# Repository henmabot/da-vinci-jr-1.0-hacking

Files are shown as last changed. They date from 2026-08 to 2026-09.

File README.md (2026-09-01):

# Da Vinci Jr. 1.0 Hacking

There was a lot of efforts on reverse engineering/hacking this printer years ago, but nobody seemed to have done it fully due to various reasons. I have decided to continue over their work, and adding my own work while documenting my progress.

This repository is a mix of:

- Organization of the old community's findings
- My own work
- Official datasheets/documentation from manufacturers

I try to add source links whenever possible.

## Status

| Task Name  | Description | Status | Main Board | Sub Board | Hotend Board |
| --- | --- | --- | --- | --- | --- |
| Pinouts | Trace all of the pinouts of the printer | 85% | 40% | 100% | 90% |
| Schematics | Draw the schematics of the printer | 85% | 30% | 100% | 100% |
| Configs | Build firmware configs for the printer  | 0% | - | - | - |

## More Information

More information can be found in the [hardware](hardware.md) and [firmware](firmware.md) sections.

In case of doubts, refer to the KiCAD schematics for pinout information. All the pinouts in the schematics are verified, while some of the docs might be outdated or have typos.

Info about my personal progress on reverse engineering can be found in the [progress](PROGRESS.md) section.

## Other Boards

This repository is mainly for Da Vinci Jr series printers, but feel free to help extend it to other boards.

## Contributing

Any kind of contribution is welcome, whether it's a bug report, a feature request, or a pull request. I am open to any kind of feedback or suggestion, and I want to make this project better for everyone.

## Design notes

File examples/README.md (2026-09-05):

# Examples

This folder contains example firmware builds that you can download and flash.

The available examples are:

- [Blink](blink.bin) ([source](https://github.com/itsyumiki/da-vinci-jr-1.0-hacking/tree/bca9b8ce5da0e177e398c52942f69a1dbfcbf0b6))
- [GPIO controller](gpiodemo.bin) ([source](../gpiodemo))

> **How to flash?**
>
> You can use [BOSSA](https://github.com/shumatech/BOSSA) to flash the firmware: `bossac -p <port> -i -e -w -v blink.bin`
>
> More instructions about flashing and erasing the chip will be added in the future.

## Blink

The Blink example is a simple firmware that blinks the top light of the board. It also has USB CDC test, and repeatedly prints the status of the X axis endstop to the serial console.

If its triggered (hotend on left side), it will report high, and if not, it will report low.

Example output:

```
hello world 1, pd8 is high
hello world 2, pd8 is high
hello world 3, pd8 is high
hello world 4, pd8 is high
hello world 5, pd8 is high
hello world 6, pd8 is high
hello world 7, pd8 is high
hello world 8, pd8 is high
hello world 9, pd8 is low
hello world 10, pd8 is low
hello world 11, pd8 is low
```

> Its source code is available [here](https://github.com/itsyumiki/da-vinci-jr-1.0-hacking/tree/bca9b8ce5da0e177e398c52942f69a1dbfcbf0b6).

## GPIO controller

The GPIO controller firmware serves the request-ID protocol used by the Rust desktop controller over USB CDC. It supports pin direction, pull-up configuration, reads, writes, change listeners, state queries, and reset.

> Its source code and protocol documentation are available [here](../gpiodemo).

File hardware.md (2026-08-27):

# Da Vinci Jr. 1.0 Hardware

To start off, there are 3 boards in the Davinci Jr. 1.0:

- [Main Board](hardware/board-main.md)
- [Sub-Board](hardware/board-sub.md)
- [Hotend-Board](hardware/board-hotend.md)

## Main Board

Main components on the main board:

- 1x Atmel SAM4E8E MCU
- 1x NXP LPC1115 MCU
- 4x Stepper drivers
- 1x 4MB Flash memory

More info about the main board can be found in the [Main Board](hardware/board-main.md) section.

## Sub-board

Main components on the sub-board:

- 1x Character LCD 4x16
- 1x SD card reader
- 6x Buttons

More info about the sub-board can be found in the [Sub-Board](hardware/board-sub.md) section.

## Hotend

Components that I was able to identify on the hotend:

- 1x Heater
- 1x NTC
- 1x Fan
- 1x Filament sensor (?)
- 1x (?)KB Flash Memory

More info on these can be found in the [Hotend](hardware/board-hotend.md) section.

## Other Hardware

The remaining components that do not belong to a board are:

- 4x NEMA17 Stepper motors
- 3x Optical endstops
- 1x Filament sensor
- 1x RFID reader
- 1x Top light bar
- 1x Reflow fan

More info on these can be found in the [Other Hardware](hardware/board-other.md) section.

## Extras

I wasn't planning to identify the cables, but i do have to identify the flex cables and sensor cables as they are needed to figure out the pinouts for the sensors, sub-board and hotend.

More information about these can be found in the [connectors](hardware/connectors.md) section.

## Notes:

- I only identified the ones that need to be defined in the firmware, so no cable or passive components for now.
- I verified the pins by first attaching an external motor/sensor and then by plugging in the stock hardware and verifying the output is the same.
- Since hotend has its own board, and its tiny, I felt like it would be more appropriate to have it as its own group than dissect it into the other groups, and mention it from other docs.
- I will create a separate sources file later as the sources list keeps growing and duplicated per-document.
- My reflow fan controller is burnt, I may or may not be able to verify its pin.

## Sources:

Please refer to [SOURCES.md](SOURCES.md) for the full list of sources.

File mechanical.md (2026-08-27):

# Da Vinci Jr. 1.0 Mechanics

Soon to be populated, this will be the part with full BOM/parts list of the printer including exact screw counts of parts etc.

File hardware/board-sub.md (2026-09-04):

# Sub-board

The sub-board is the board for the interactivity of the printer. It has **6 push buttons, a 16x4 LCD display, and a full-size SD card slot**. It also has a **16 pin connector** labeled "SD CARD SLOT CONNECTOR", and a **22 pin connector** labeled "LCM SLOT CONNECTOR". It has no visible MCU's, only some power related chips and components. It also has no visible unpopulated headers, connectors and chip sockets.

| Front view of the board | Back view of the board |
| --- | --- |
| Front view | Back view |
| Front desoldered view | |

The board is **62mm to 185mm** in size.

**The components that i was able to identify so far are:**

- **1x** Winstar WH1604A 16x04 LCD module
- **1x** Generic SD card reader module
- **6x** Generic 6mm push buttons

There are some more chips that i didnt see as important, as they are passive or hardware driven. More information about these can be found in the [schematic](../schematic.md).

More information about the connectors on-board can be found in the [connectors](connectors.md) section.

## Winstar WH1604A 16x04 LCD module

The Winstar WH1604A 16x04 LCD module is a character LCD display that is used to display text on the sub-board. It has 16 columns and 4 rows of characters, and is connected to the main board via a 22 pin connector labeled "LCM SLOT CONNECTOR".

Refer to the [Winstar WH1604A 16x04 LCD Module Datasheet](../SOURCES.md#datasheet-winstar-wh1604a) for more information.

### Pinout

The connector mentioned here is the 22 pin connector.

| Pin | Name | Description | Connector Pin | Verified? | MCU Pin | Verified? |
| --- | ---- | --- | --- | --- | --- | --- |
| 01  | VSS  | Ground | GND | ✅ | GND | ✅ |
| 02  | VDD  | Supply Voltage for logic | 5V | ✅ | 5V | ✅ |
| 03  | VO | Operating voltage | - | ✅ | - | - |
| 04  | RS | H: DATA, L: Instruction code | 05 | ✅ |
| 05  | R/W  | H: Read L: Write | 04 | ✅ |
| 06  | E | Chip enable signal | 03 | ✅ |
| 07  | DB0  | Data bus line | 06 | ✅ |
| 08  | DB1  | Data bus line | 07 | ✅ |
| 09  | DB2  | Data bus line | 08 | ✅ |
| 10  | DB3  | Data bus line | 09 | ✅ |
| 11  | DB4  | Data bus line | 10 | ✅ |
| 12  | DB5  | Data bus line | 11 | ✅ |
| 13  | DB6  | Data bus line | 12 | ✅ |
| 14  | DB7  | Data bus line | 13 | ✅ |
| 15  | A | Backlight + | 5V | ✅ |
| 16  | K | Backlight - | 14 | ✅ |

### Photos

| Front view | Back view |
| --- | --- |
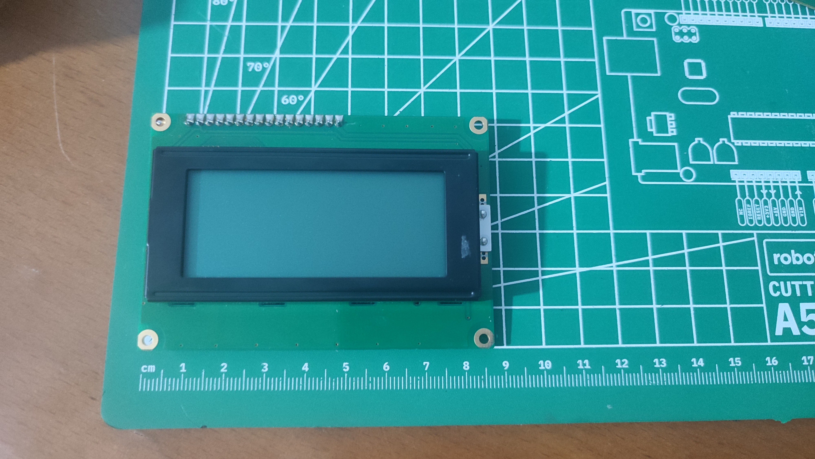
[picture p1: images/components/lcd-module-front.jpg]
Front view
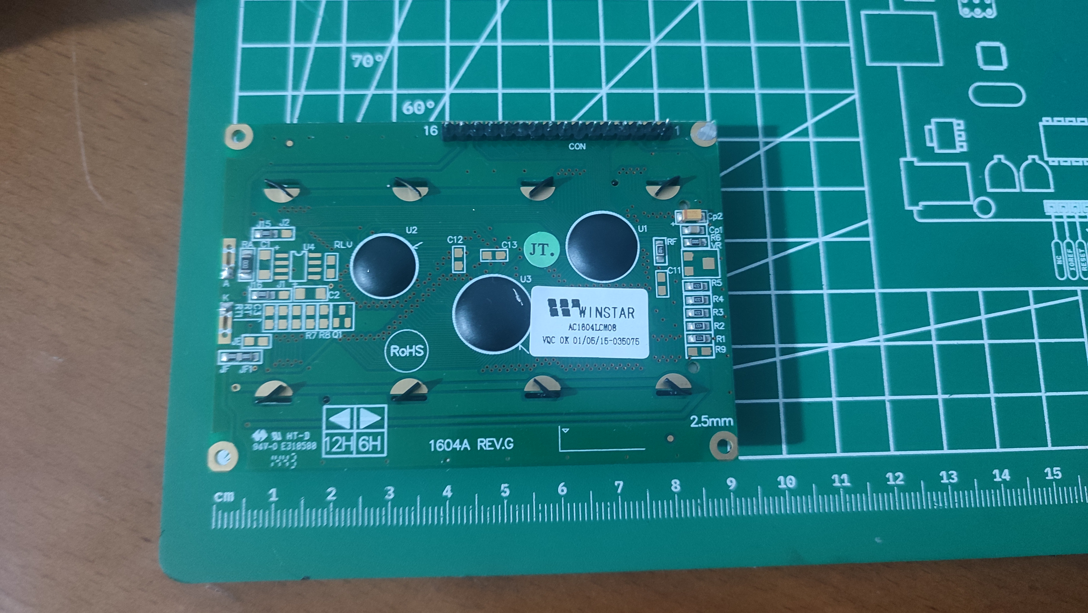
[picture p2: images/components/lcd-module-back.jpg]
Back view
|  |  |

## SD Card Reader Module

The SD card reader module is used to read full size SD cards and is connected to the main board via a 16 pin connector labeled "SD CARD SLOT CONNECTOR".

The WP and CD pins are grounded when they are triggered, like:

- No card inserted: CD is grounded
- Card inserted but write-protected: WP is grounded
- Card inserted and not write-protected: Both are floating/non-grounded

It is a generic SD card reader module, so there is no specific datasheet available.

### Pinout

Pins start from P1 (on the right of the reader) and go to the left, up to P11.

The connector mentioned here is the 16 pin connector.

| Pin | Name | Description | Connector Pin | Verified? | MCU Pin | Verified? |
| --- | --- | --- | --- | --- | --- | --- |
| 01  | DAT2 | - | 16 | ✅ | PA26 | ✅ |
| 02  | CS/DAT3 | Chip Select | 14 | ✅ | PA27 | ✅ |
| 03  | CMD | MOSI/Data in | 12 | ✅ | PA28 | ✅ |
| 04  | VSS1 | Ground | GND | ✅ | GND | ✅ |
| 05  | VDD | Power | 09 | ✅ | 3.3V | ✅ |
| 06  | CLK | SCK | 07 | ✅ | PA29 | ✅ |
| 07  | VSS2 | Ground | GND | ✅ | GND | ✅ |
| 08  | DAT0 | MISO | 05 | ✅ | PA30 | ✅ |
| 09  | DAT1 | - | 03 | ✅ | PA31 | ✅ |
| 10  | WP | Write Protect lock | - | ✅ | - | ✅ |
| 11  | CD | Card Detect | 10 | ✅ | PA25 | ✅ |

### Photos

| Top view of the SD card reader                       |
| ---------------------------------------------------- |
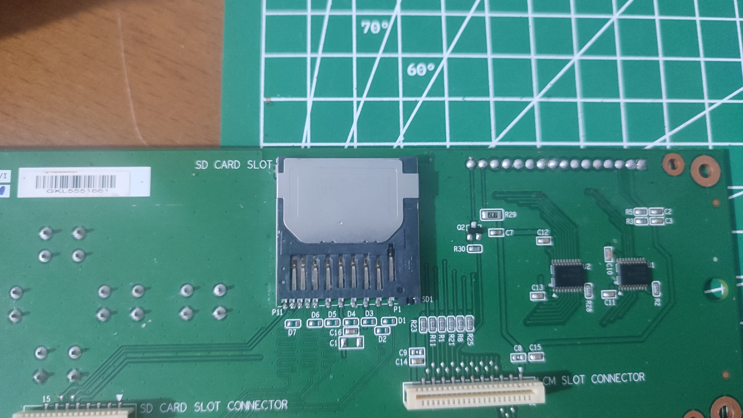
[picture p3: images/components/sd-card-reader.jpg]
|  |

## Push Buttons

The push buttons are used to control the sub-board and are connected to the main board via one of the existing connectors.

They are pulled up to 5V and grounded when pressed.

I doubt a datasheet for a button would be useful even.

### Pinout

The connector mentioned here is the 22 pin connector.

| Button | Name | Description  | Connector Pin | Verified? | MCU Pin | Verified? |
| --- | --- | --- | --- | --- | --- | --- |
| SW1 | UP | Up button | 18 | ✅ | PE1 | ✅ |
| SW2 | DOWN | Down button  | 16 | ✅ | PA21 | ✅ |
| SW3 | RIGHT  | Right button | 19 | ✅ | PE4 | ✅ |
| SW4 | LEFT | Left button  | 17 | ✅ | PB3 | ✅ |
| SW5 | ENTER  | Enter button | 20 | ✅ | PA17 | ✅ |
| SW6 | ESCAPE | Home button  | 15 | ✅ | PD30 | ✅ |

### Photos

| Top view of the push buttons                       |
| -------------------------------------------------- |
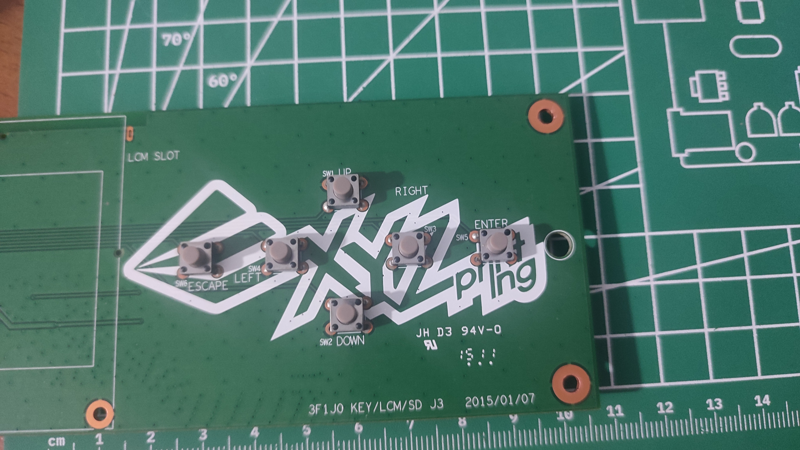
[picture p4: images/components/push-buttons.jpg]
|  |

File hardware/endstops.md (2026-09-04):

# Optical Endstops

There are 3 optical endstops on the printer. They share one connector labeled "Home Sensor".

## Pinout

| Pin Name  | MCU | Pin Desc | Verified? |
| --- | --- | --- | --- |
| X Endstop | 113 | PD8 | ✅ |
| Y Endstop | 117 | PC19 | ✅ |
| Z Endstop | 110 | PD9 | ✅ |

They are high when triggered, low when idle. They have hardware pull-up resistors on them. I am unsure about software pull-up being redundant.

## Photos

| In this photo all the endstops are visible after removal.          |
| ------------------------------------------------------------------ |
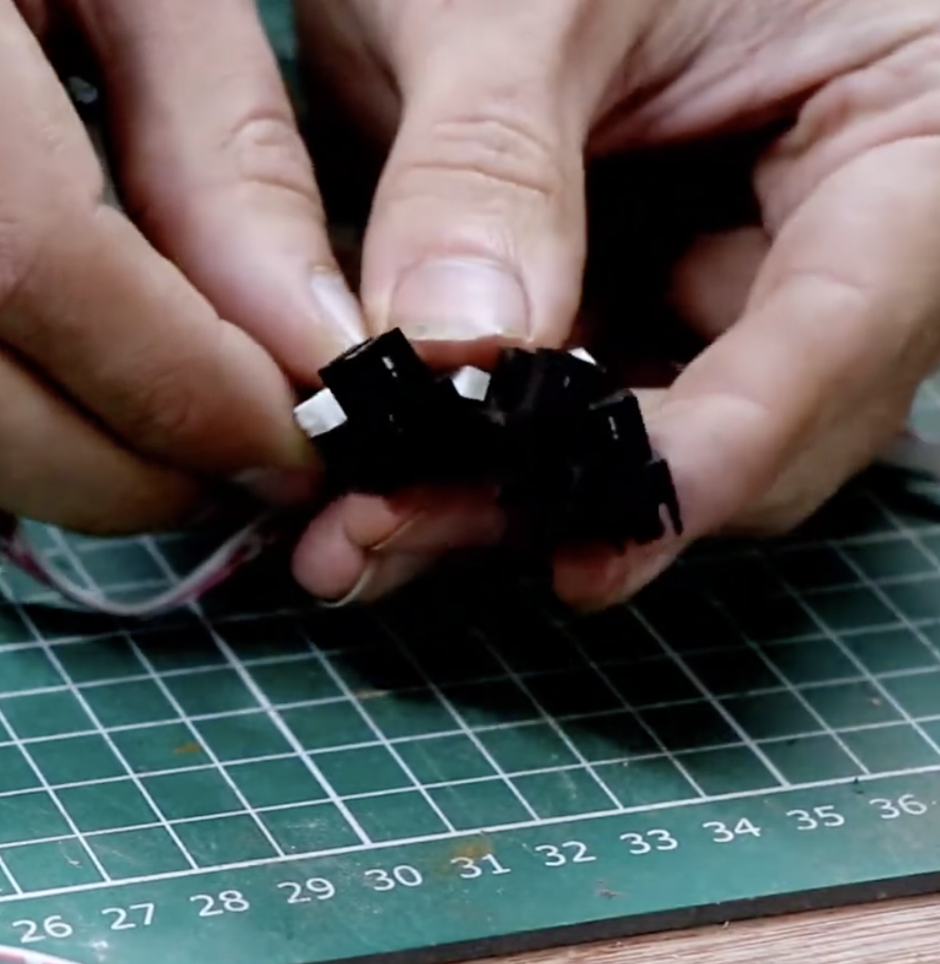
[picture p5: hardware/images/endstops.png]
All endstops after removal (YT)
|  |

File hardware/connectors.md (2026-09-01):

# Connectors

There are 3 main data connectors on the Da Vinci Jr 1.0 board.

- 22-pin LCD connector
- 16-pin SD Card connector
- 51-pin Hotend connector

There are of course a lot more connectors on board, but these are the main ones needing identification.

## 51-pin Hotend connector

The 51-pin Hotend connector connects the main board with the hotend. Its mostly power wires, and a few data wires.

### Photos

| Main board connector | Sub-board connector |
| --- | --- |
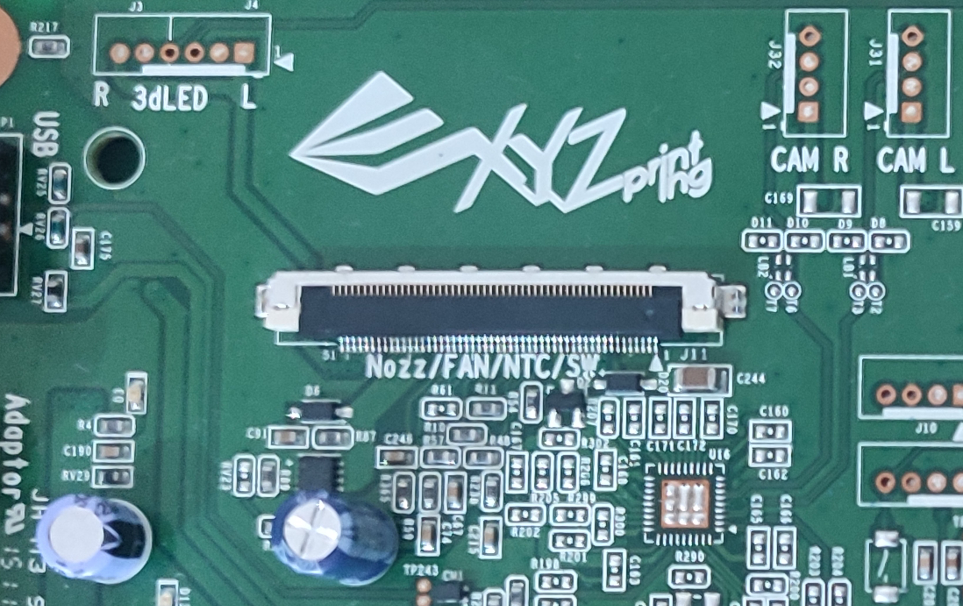
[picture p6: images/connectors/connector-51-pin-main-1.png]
Main board with text visible
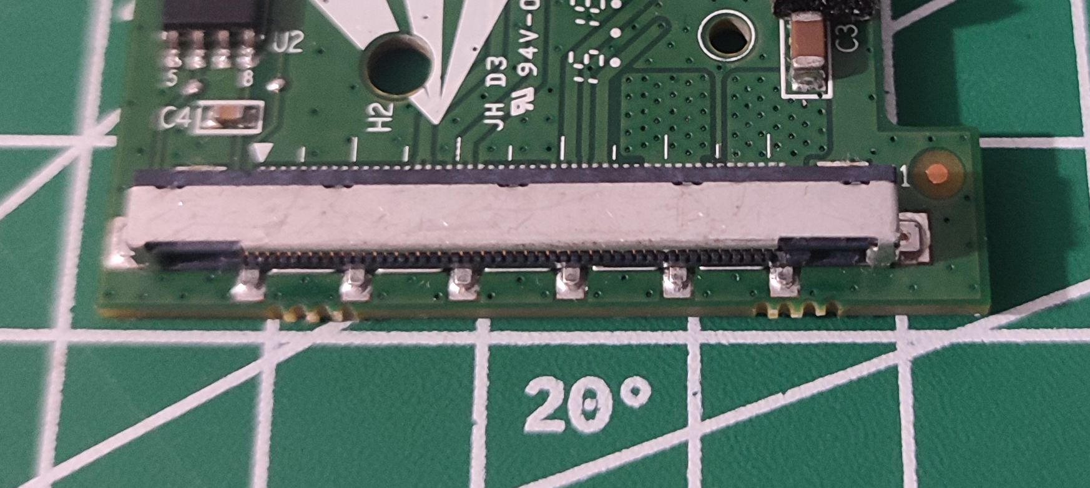
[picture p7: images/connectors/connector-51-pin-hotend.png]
|  |  |
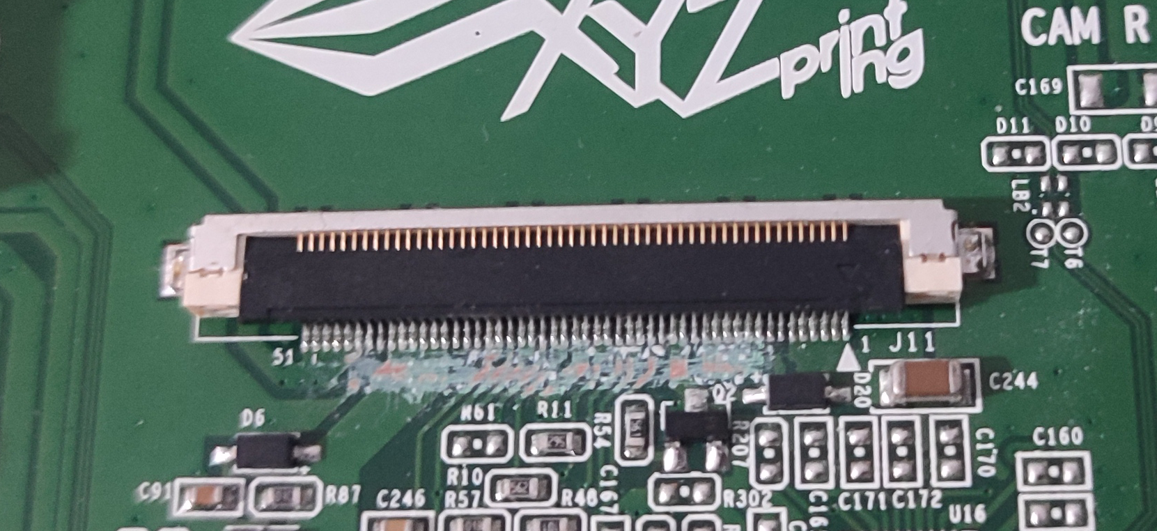
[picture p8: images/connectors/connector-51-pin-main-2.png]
Main board without text
|  | |

### Pinout

> Pins 1-6 and 46-51 are connected to each other, and they connect to the power via a fuse labeled R292 on board.
>
> IR sensor is the filament sensor. Its other end is connected to GND on the hotend, and its active low.
>
> J5 is a connector that I have no idea what it is for yet. I'm guessing its for calibrating the bed.

| Pin | Main board | Description | Verified? | Hotend | Description | Verified? |
| --- | --- | --- | --- | --- | --- | --- |
| 01  | 12V | Power 12V | ✅ | - | Not connected | ✅ |
| 02  | 12V | Power 12V | ✅ | - | Not connected | ✅ |
| 03  | 12V | Power 12V | ✅ | - | Not connected | ✅ |
| 04  | 12V | Power 12V | ✅ | - | Not connected | ✅ |
| 05  | 12V | Power 12V | ✅ | - | Not connected | ✅ |
| 06  | 12V | Power 12V | ✅ | - | Not connected | ✅ |
| 07  | - | Not connected | ✅ | - | Not connected | ✅ |
| 08  | - | Not connected | ✅ | - | Not connected | ✅ |
| 09  | Q8 5-8 | Mosfet drain  | ✅ | - | Not connected | ✅ |
| 10  | Q8 5-8 | Mosfet drain  | ✅ | - | Not connected | ✅ |
| 11  | Q8 5-8 | Mosfet drain  | ✅ | - | Not connected | ✅ |
| 12  | Q8 5-8 | Mosfet drain  | ✅ | - | Not connected | ✅ |
| 13  | Q8 5-8 | Mosfet drain  | ✅ | - | Not connected | ✅ |
| 14  | Q8 5-8 | Mosfet drain  | ✅ | - | Not connected | ✅ |
| 15  | - | Not connected | ✅ | - | Not connected | ✅ |
| 16  | Q2 3 | Transistor C  | ✅ | J2 1 | Fan GND | ✅ |
| 17  | Q2 3 | Transistor C  | ✅ | J2 1 | Fan GND | ✅ |
| 18  | - | Not connected | ✅ | - | Not connected | ✅ |
| 19  | - | - | ❌ | GND | Ground | ✅ |
| 20  | - | - | ❌ | U1 3 | IR Signal | ✅ |
| 21  | - | - | ❌ | U1 3 | IR Signal | ✅ |
| 22  | - | - | ❌ | GND | Ground | ✅ |
| 23  | - | - | ❌ | U2 5 | EEPROM SDA | ✅ |
| 24  | - | - | ❌ | U2 5 | EEPROM SDA | ✅ |
| 25  | | - | ❌ | U2 8 | EEPROM VCC | ✅ |
| 26  | - | - | ❌ | U2 8 | EEPROM VCC | ✅ |
| 27  | - | - | ❌ | U2 6 | EEPROM SCL | ✅ |
| 28  | - | - | ❌ | U2 6 | EEPROM SCL | ✅ |
| 29  | - | - | ❌ | GND | Ground | ✅ |
| 30  | - | - | ❌ | J3 1 | NTC signal | ✅ |
| 31  | - | - | ❌ | J3 1 | NTC signal | ✅ |
| 32  | GND | Ground | ✅ | GND | Ground | ✅ |
| 33  | - | - | ❌ | J5 1 | Unknown conn  | ✅ |
| 34  | - | - | ❌ | J5 1 | Unknown conn  | ✅ |
| 35  | - | Not connected | ✅ | - | Not connected | ✅ |
| 36  | - | Not connected | ✅ | - | Not connected | ✅ |
| 37  | - | Not connected | ✅ | - | Not connected | ✅ |
| 38  | Q8 5-8 | Mosfet drain  | ✅ | J4 1 | Heater GND | ✅ |
| 39  | Q8 5-8 | Mosfet drain  | ✅ | J4 1 | Heater GND | ✅ |
| 40  | Q8 5-8 | Mosfet drain  | ✅ | J4 1 | Heater GND | ✅ |
| 41  | Q8 5-8 | Mosfet drain  | ✅ | J4 1 | Heater GND | ✅ |
| 42  | Q8 5-8 | Mosfet drain  | ✅ | J4 1 | Heater GND | ✅ |
| 43  | Q8 5-8 | Mosfet drain  | ✅ | J4 1 | Heater GND | ✅ |
| 44  | - | Not connected | ✅ | - | Not connected | ✅ |
| 45  | - | Not connected | ✅ | - | Not connected | ✅ |
| 46  | 12V | Power 12V | ✅ | 12V | Power 12V | ✅ |
| 47  | 12V | Power 12V | ✅ | 12V | Power 12V | ✅ |
| 48  | 12V | Power 12V | ✅ | 12V | Power 12V | ✅ |
| 49  | 12V | Power 12V | ✅ | 12V | Power 12V | ✅ |
| 50  | 12V | Power 12V | ✅ | 12V | Power 12V | ✅ |
| 51  | 12V | Power 12V | ✅ | 12V | Power 12V | ✅ |

## 22-pin LCD connector

The 22-pin LCD connector connects the main board with the sub-board, and carries the LCD display data. It also carries the buttons signals.

### Photos

| Main board connector | Sub-board connector |
| --- | --- |
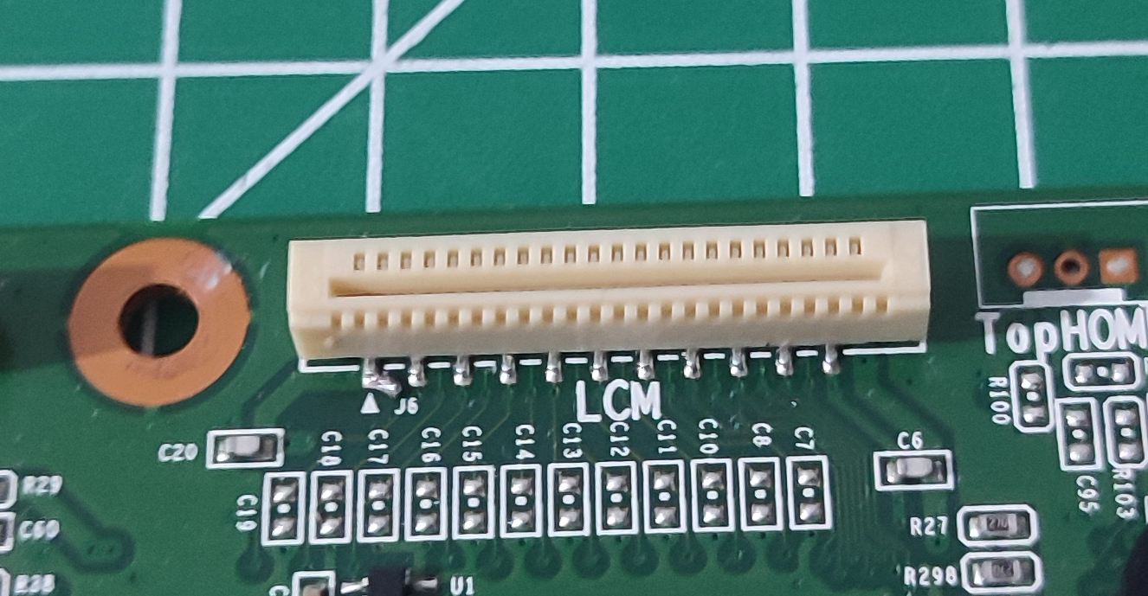
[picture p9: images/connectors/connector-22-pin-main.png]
Main board
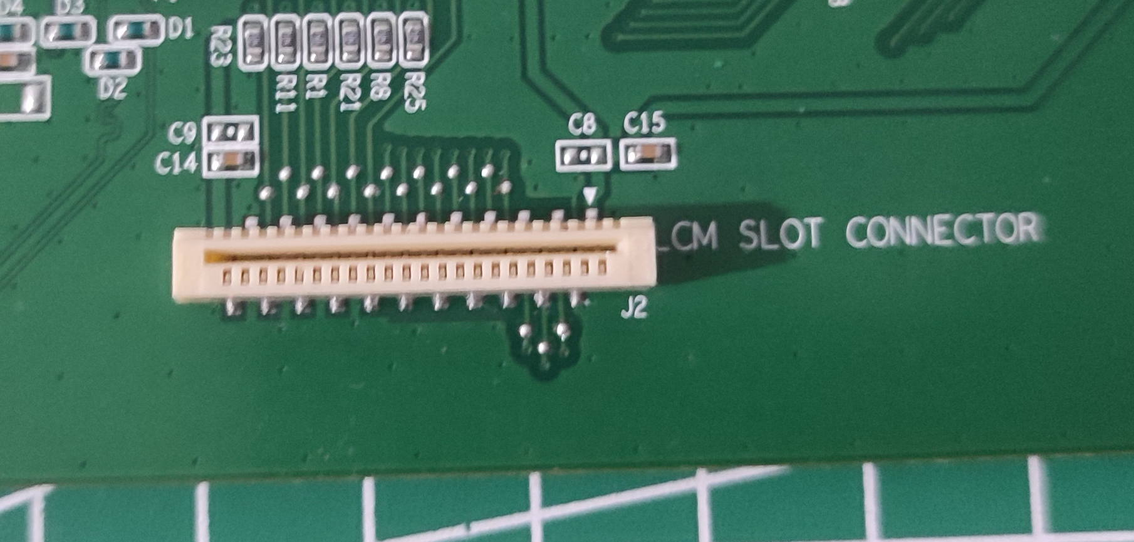
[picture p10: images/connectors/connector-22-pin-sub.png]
|  |  |

### Pinout

| Pin | Main Board | Description | Verified? | Sub-board | Description | Verified? |
| --- | --- | --- | --- | --- | --- | --- |
| 01  | +5V | 5V Power | ✅ | 5V | 5V power | ✅ |
| 02  | GND | Ground | ✅ | GND | Ground | ✅ |
| 03  | 111 | PC18 | ❌ | E | LCD enable | 🚧 |
| 04  | 82 | PC8 | ❌ | R/W | LCD R/W | 🚧 |
| 05  | U1_Pin1 | ??? | ❌ | RS | LCD RS | 🚧 |
| 06  | 11 | PC0 | ❌ | D0 | LCD data bus  | 🚧 |
| 07  | 38 | PC1 | ❌ | D1 | LCD data bus  | 🚧 |
| 08  | 39 | PC2 | ❌ | D2 | LCD data bus  | 🚧 |
| 09  | 40 | PC3 | ❌ | D3 | LCD data bus  | 🚧 |
| 10  | 41 | PC4 | ❌ | D4 | LCD data bus  | 🚧 |
| 11  | 58 | PC5 | ❌ | D5 | LCD data bus  | 🚧 |
| 12  | 54 | PC6 | ❌ | D6 | LCD data bus  | 🚧 |
| 13  | 48 | PC7 | ❌ | D7 | LCD data bus  | 🚧 |
| 14  | 90 | PC10 | ❌ | LCD | LCD backlight | 🚧 |
| 15  | 34 | VDDCORE | ❌ | ESCAPE | Home button | ✅ |
| 16  | 32 | PA21/PGMD9  | ❌ | DOWN | Down button | ✅ |
| 17  | 31 | PB3 | ❌ | LEFT | Left button | ✅ |
| 18  | 28 | PE5 | ❌ | UP | Up button | ✅ |
| 19  | 27 | PE4 | ❌ | RIGHT | Right button  | ✅ |
| 20  | 25 | PA17/PGMD5  | ❌ | ENTER | Enter button  | ✅ |
| 21  | GND | Ground | ❌ | GND | Ground | ✅ |
| 22  | +5V | Power | ❌ | 5V | 5V Power | ✅ |

## 16-pin SD Card connector

The 16-pin LCD connector connects the main board with the sub-board, and carries the SD card data.

### Photos

| Main board connector | Sub-board connector |
| --- | --- |
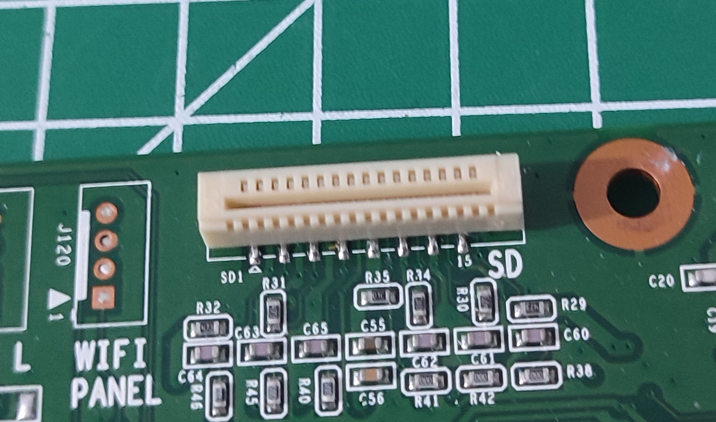
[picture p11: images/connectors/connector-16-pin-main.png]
Main board
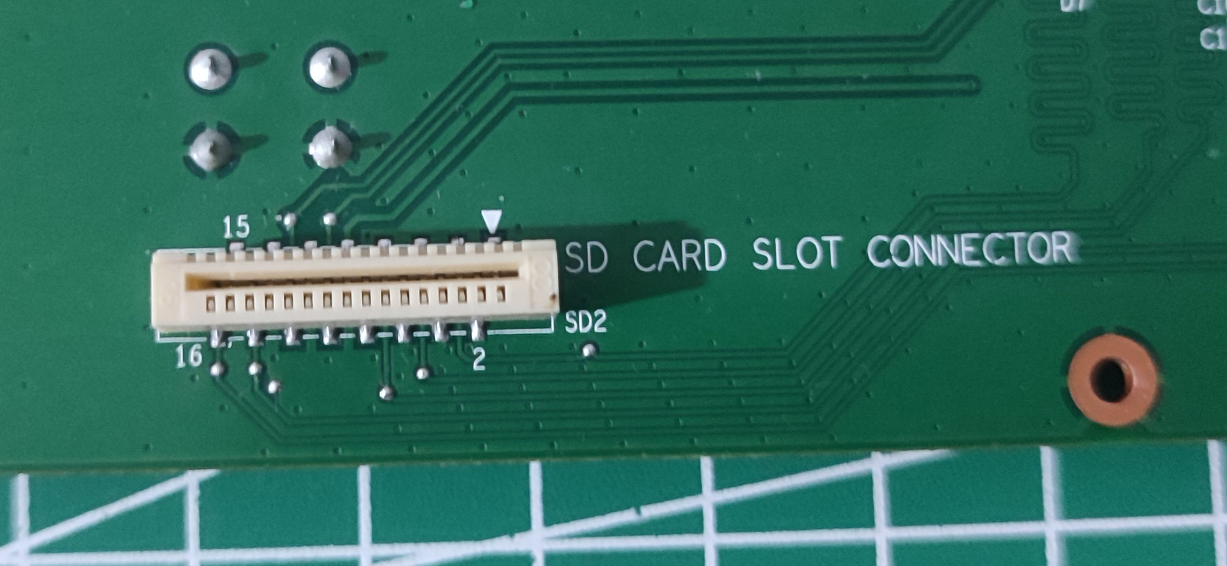
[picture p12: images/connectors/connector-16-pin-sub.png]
|  |  |

### Pinout

| Pin | Main Board | Description | Verified? | Sub-board | Description | Verified? |
| --- | --- | --- | --- | --- | --- | --- |
| 01  | - | Not connected | ✅ | - | Not connected | ✅ |
| 02  | GND | Ground | ✅ | GND | Ground | ✅ |
| 03  | 118 | PA31/MCDA1 | ❌ | DAT1 | SD Card DAT1  | ✅ |
| 04  | GND | Ground | ✅ | GND | Ground | ✅ |
| 05  | 116 | PA30/MCDA0 | ❌ | DAT0 | SD Card DAT0  | ✅ |
| 06  | GND | Ground | ✅ | GND | Ground | ✅ |
| 07  | 129 | PA29/MCCK | ❌ | CLK | SD Card CLK | ✅ |
| 08  | +3.3V | Power | ❌ | +3.3V | 3.3V Power | ✅ |
| 09  | +3.3V | Power | ❌ | +3.3V | 3.3V Power | ✅ |
| 10  | 59 | PA25/PGMD13/CTS1  | ❌ | CD | Card detect | ✅ |
| 11  | GND | Ground | ❌ | GND | Ground | ✅ |
| 12  | 112 | PA28/MCCDA | ❌ | CMD | SD Card CMD | ✅ |
| 13  | GND | Ground | ❌ | GND | Ground | ✅ |
| 14  | 70 | PA27/PGMD15/MCDA3 | ❌ | DAT3 | SD Card DAT3  | ✅ |
| 15  | GND | Ground | ❌ | GND | Ground | ✅ |
| 16  | 62 | PA28/PGMD14/MCDA2 | ❌ | DAT2 | SD Card DAT2  | ✅ |

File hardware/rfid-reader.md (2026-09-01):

# RFID Reader

I am working on the pinout as the secondary MCU firmware uses it and I need to map the pins.
More details are available [here](https://youtu.be/cn2mYWmanlk?t=556).

The important chip on this board is **PN512 NFC Chip**.

| Front view without the shield | Back view of the board |
| --- | --- |
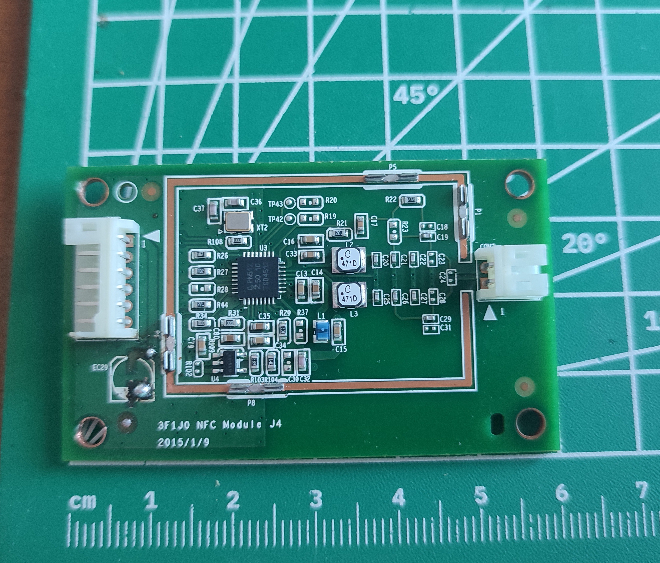
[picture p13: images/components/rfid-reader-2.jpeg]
Front view
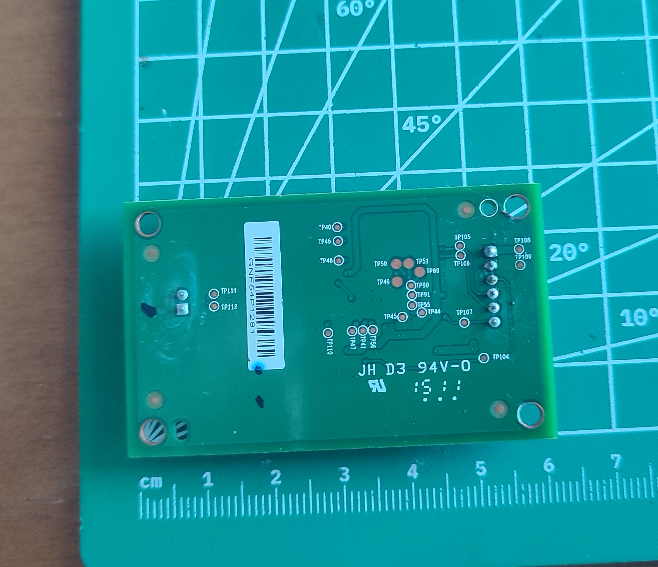
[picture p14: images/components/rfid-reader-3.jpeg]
Back view
|  |  |

| Front view of the board while its mounted (YouTube) | Back view of the board while its mounted (Reddit) | Front view of the board while its mounted (Reddit) | Back view of the board while its mounted (Reddit) |
| --- | --- | --- | --- |
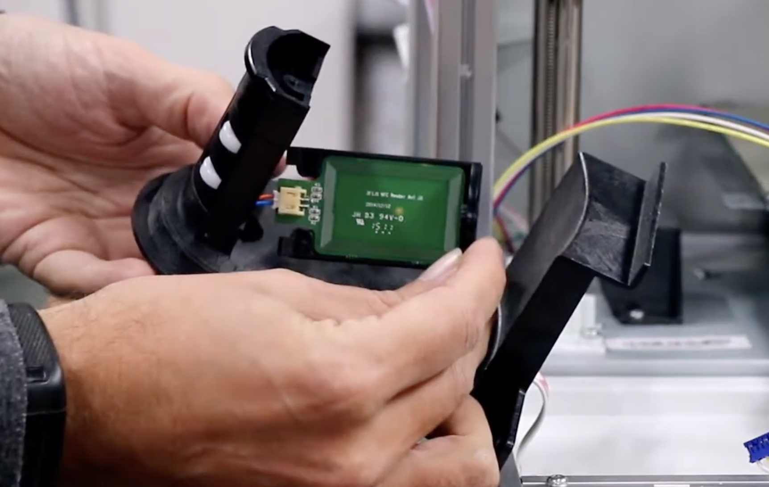
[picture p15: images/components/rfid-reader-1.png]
Front view (YT)
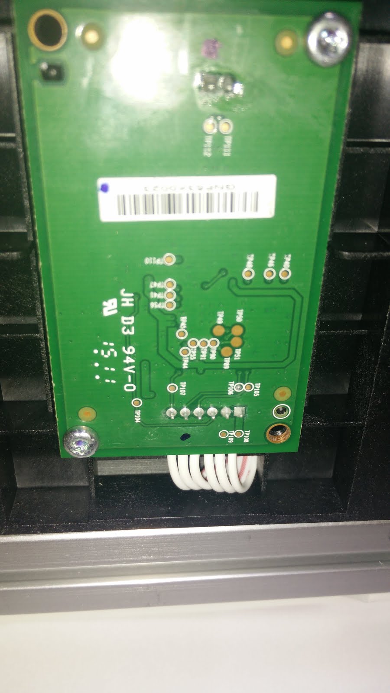
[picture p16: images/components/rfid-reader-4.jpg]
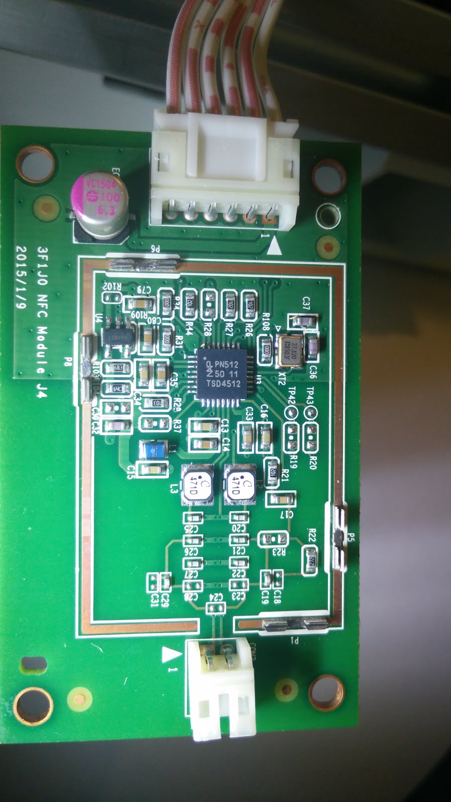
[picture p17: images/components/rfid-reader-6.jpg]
Front view (Reddit)
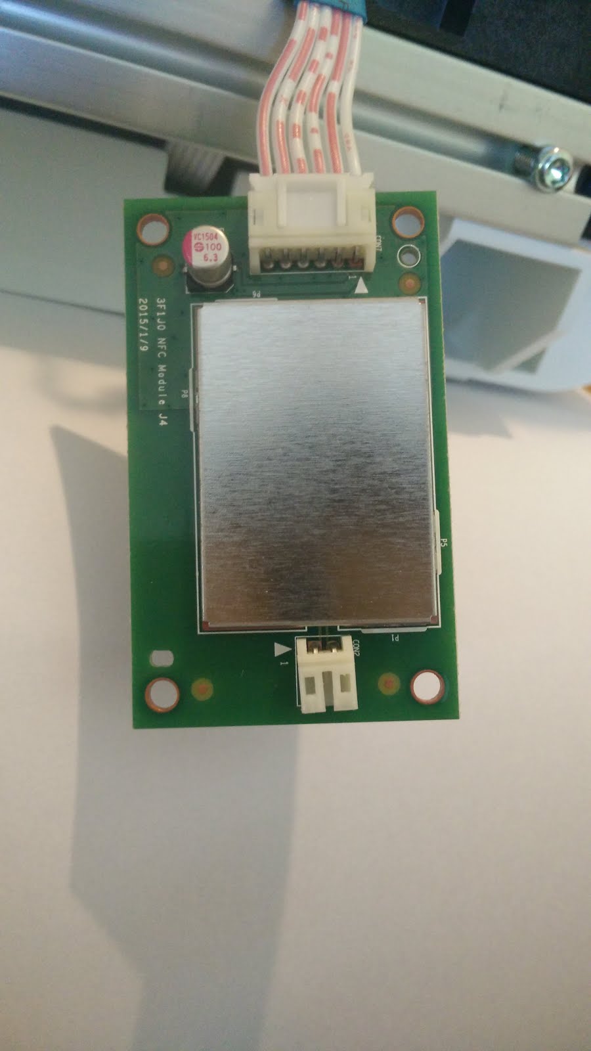
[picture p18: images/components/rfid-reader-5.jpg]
|  |  |  |  |

The board is **60mm to 36.5mm** in size. It seems to share the other characteristics of the other PCB's.

### Pinout

The board has a 6 pin connector going to the main board, and a 2 pin antenna connector. We only need the 6 pin connector.

From what i know so far, it probably connects to the secondary MCU.

| Pin | Name | Description | MCU | Pin Desc | Verified? |
| --- | --- | --- | --- | --- | --- |
| 01  | VIN | Power input | | | ❌ |
| 02  | GND | Ground | | | ✅ |
| 03  | NRSTPD | | | | ❌ |
| 04  | ALE | | | | ❌ |
| 05  | IRQ | | | | ❌ |
| 06  | D7 | | | | ❌ |

## PN512 NFC Chip

Refer to the [NXP PN512 Datasheet](../SOURCES.md#datasheet-nxp-pn512) for more information.

### Pinout

It can be found in the [datasheet](../SOURCES.md#datasheet-nxp-pn512).

### Photos

| 32 Pin HVQFN package PN512 chip from top-view. First pin starts on the top of the left side, and goes counterclockwise | Datasheet diagram |
| --- | --- |
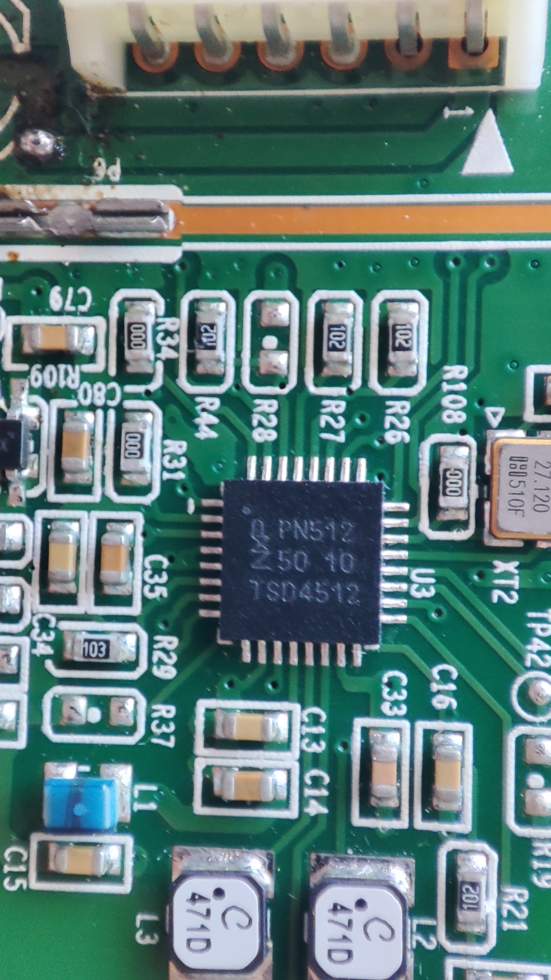
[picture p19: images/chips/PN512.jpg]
Top view
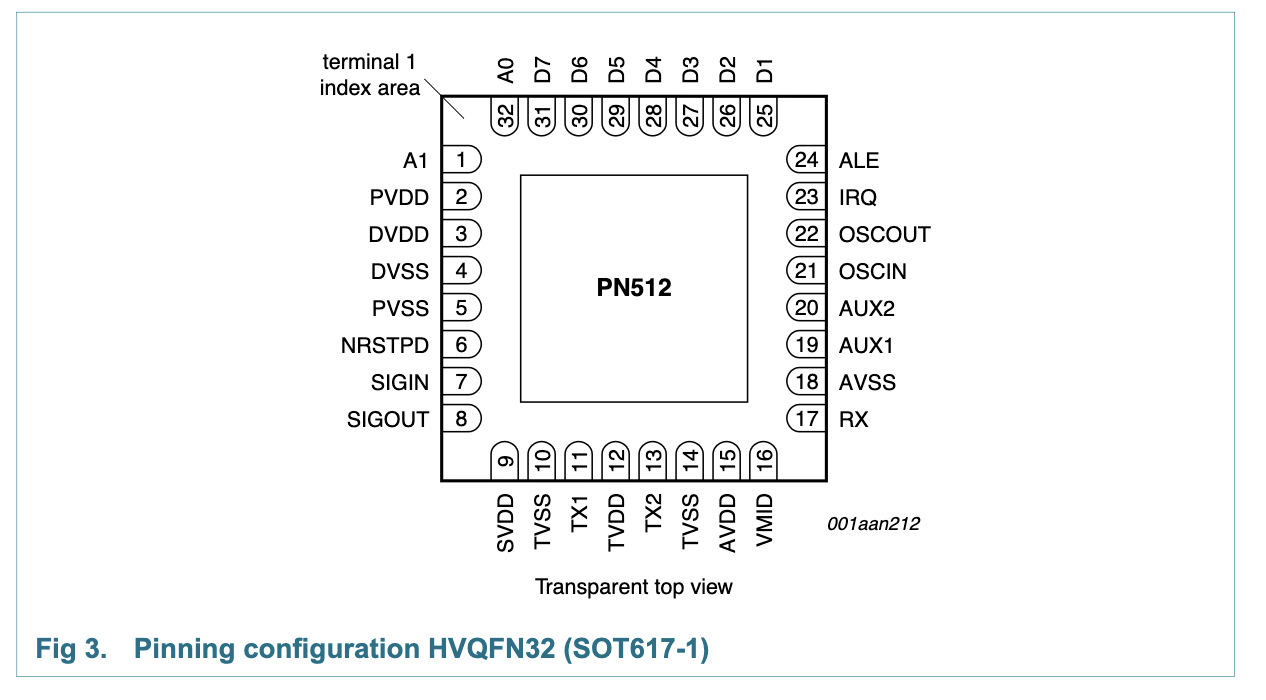
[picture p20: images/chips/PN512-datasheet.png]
Datasheet diagram
|  |  |

## Extras

This board also has a LDO regulator (RT9179). It took me some time to figure out the chip since its very small and a discontinued part.

Information about the chip can be found [here](https://basicaodaeletronica.com.br/smd/pdfs/rt9179_richtek.pdf). I wont add it to sources as its not a mission-critical part, but it is still important when tracing the pins for this specific board.

It has 68 kΩ to Vout, 45.3 kΩ to GND; which calculates to a little below 3.0V.

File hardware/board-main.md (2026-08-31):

# Main Board

The main board is the brain of the printer. It has **2 MCU's, a 4MB Flash memory, 4 stepper drivers**, various voltage regulators and some crystal oscillators. It has a lot of unpopulated headers, connectors and chip sockets, mainly for other versions of the device that use the same board. There are also some debug headers and connectors.

| Front view of the board | Back view of the board |
| --- | --- |
| Front view | Back view |

The board is **100mm to 240mm** in size without the headers and connectors. It seems to be only dual layer, which makes it easier to work with. It is 1.5mm thick.

**The components that i was able to identify so far are:**

- **1x** Atmel SAM4E8E MCU
- **1x** NXP LPC1115 MCU
- **4x** Toshiba TB62269FTG Stepper driver
- **1x** Macronix MX25L3206E 4MB Flash memory
- **1x** AC-1203D RP1 Buzzer

**The ones awaiting identification are:**

- **2x** 12.000 Hz crystal oscillators
- **1x** unmarked crystal oscillator (for RTC?)

There are some more chips that i didnt see as important, as they are passive or hardware driven.

## Atmel SAM4E8E MCU

A 32-bit ARM Cortex-M4 MCU with FPU, DSP instructions and Thumb-2 instruction set. It can run at up to 120 MHz.

It has:

- **512KB Flash**
- **128KB SRAM**
- **16KB ROM** with embedded boot loader (UART) and IAP routines
- **117 GPIO pins** available
- **12-bit ADC and DAC** natively, that can sample up to **1 Msps**
- Possible to go up to 16-bit via oversampling

Refer to the [Atmel SAM4E Datasheet](../SOURCES.md#datasheet-atmel-sam4e8e) for more information.

### Pinout

It can be found here: [sam4e8e-pinout.md](pinouts/sam4e8e-pinout.md)

### Photos

| 144 Pin LQFP package SAM4E8E chip from top-view. First pin starts on the left of the bottom side, and goes counterclockwise. | Datasheet diagram (no pin numbers). |
| --- | --- |
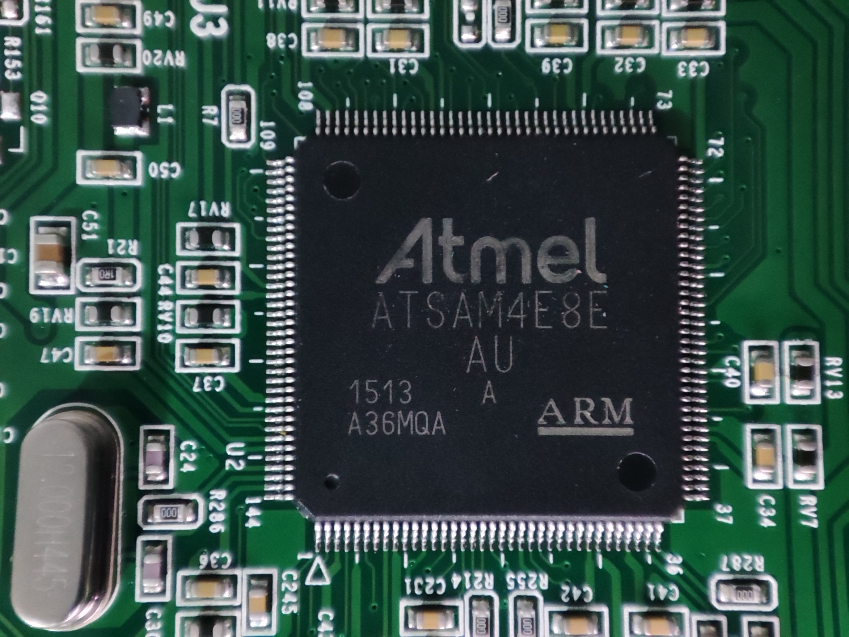
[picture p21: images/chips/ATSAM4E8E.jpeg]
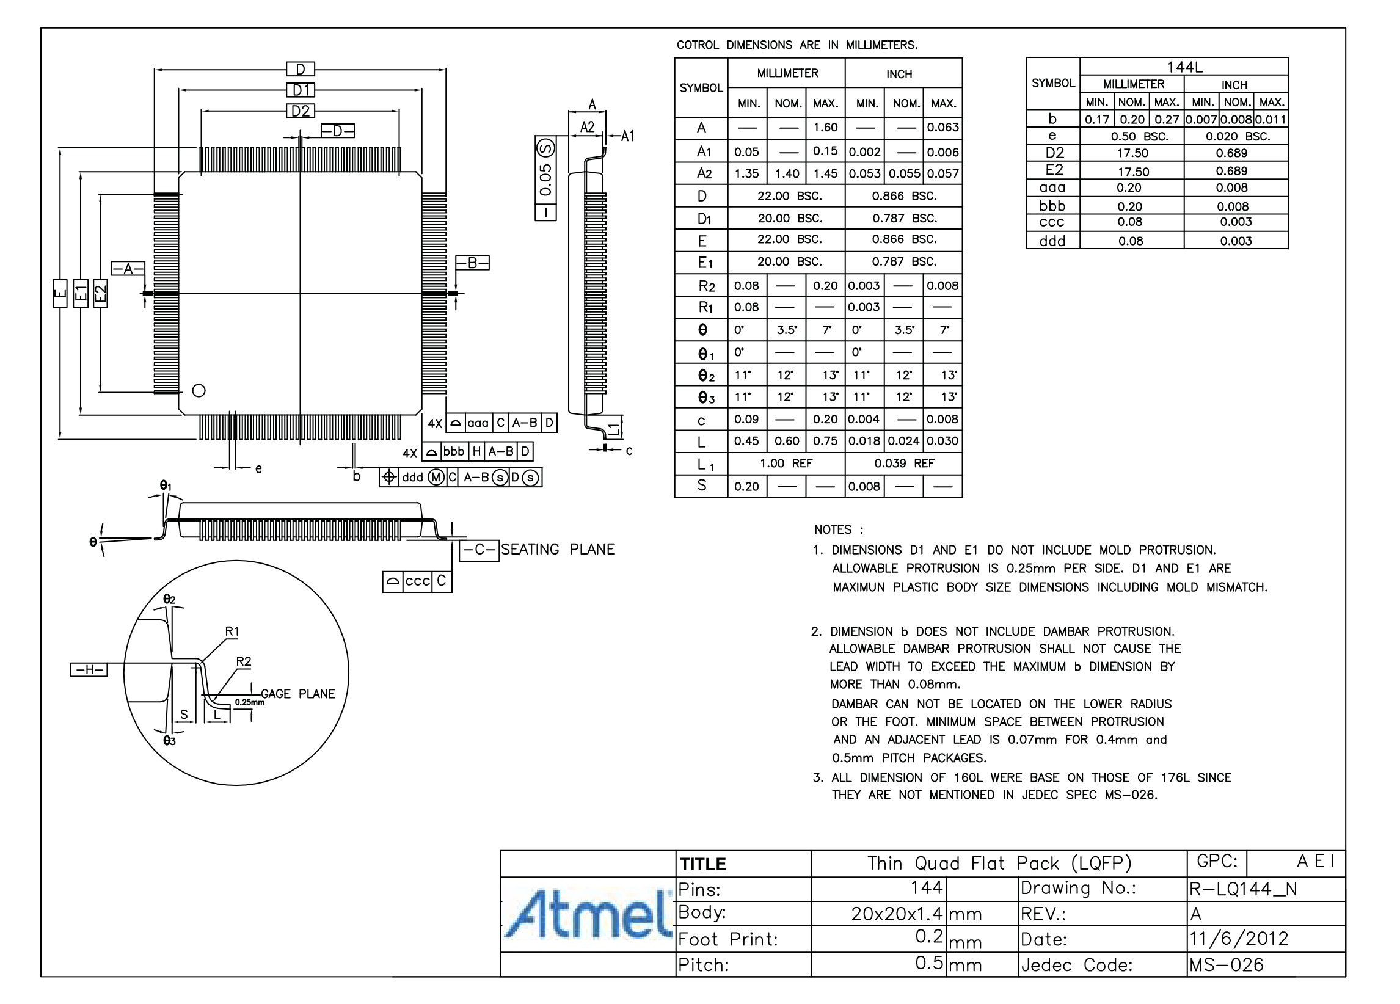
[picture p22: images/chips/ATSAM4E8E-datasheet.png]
Datasheet diagram
|  |  |

## NXP LPC1115 MCU

A 32-bit ARM Cortex-M0 MCU with Thumb instruction set. It can run at up to 50 MHz.

It has:

- **64KB of Flash**
- **8KB of SRAM**
- **16KB of ROM** with embedded boot loader (UART) and IAP routines
- **Up to 42 GPIO pins** available
- **10-bit ADC**, no confirmed DAC
-

Refer to the [NXP LPC111x Datasheet](../SOURCES.md#datasheet-nxp-lpc111x) for more information.

### Pinout

It can be found here: [lpc1115-pinout.md](pinouts/lpc1115-pinout.md)

### Photos

| 48 Pin LQFP package LPC1115 chip from top-view. First pin starts on the left of the bottom side, and goes counterclockwise. | Datasheet diagram with the first pin on top of the left side. |
| --- | --- |
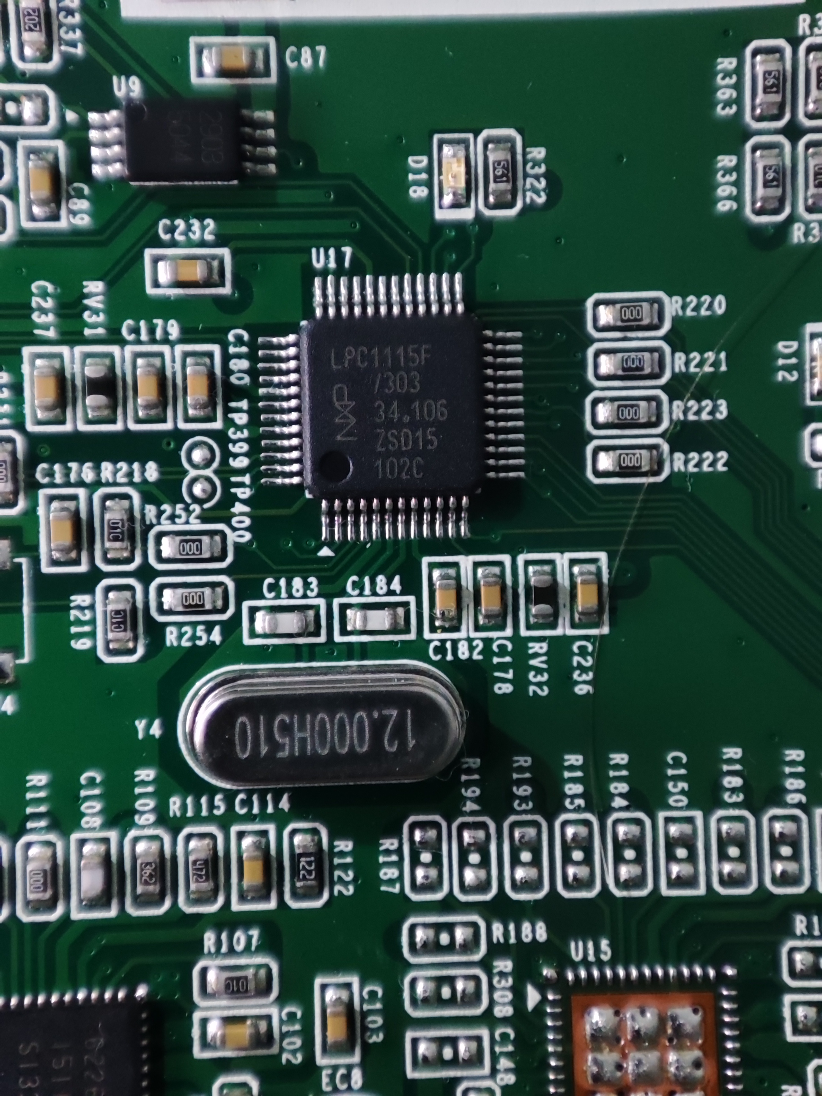
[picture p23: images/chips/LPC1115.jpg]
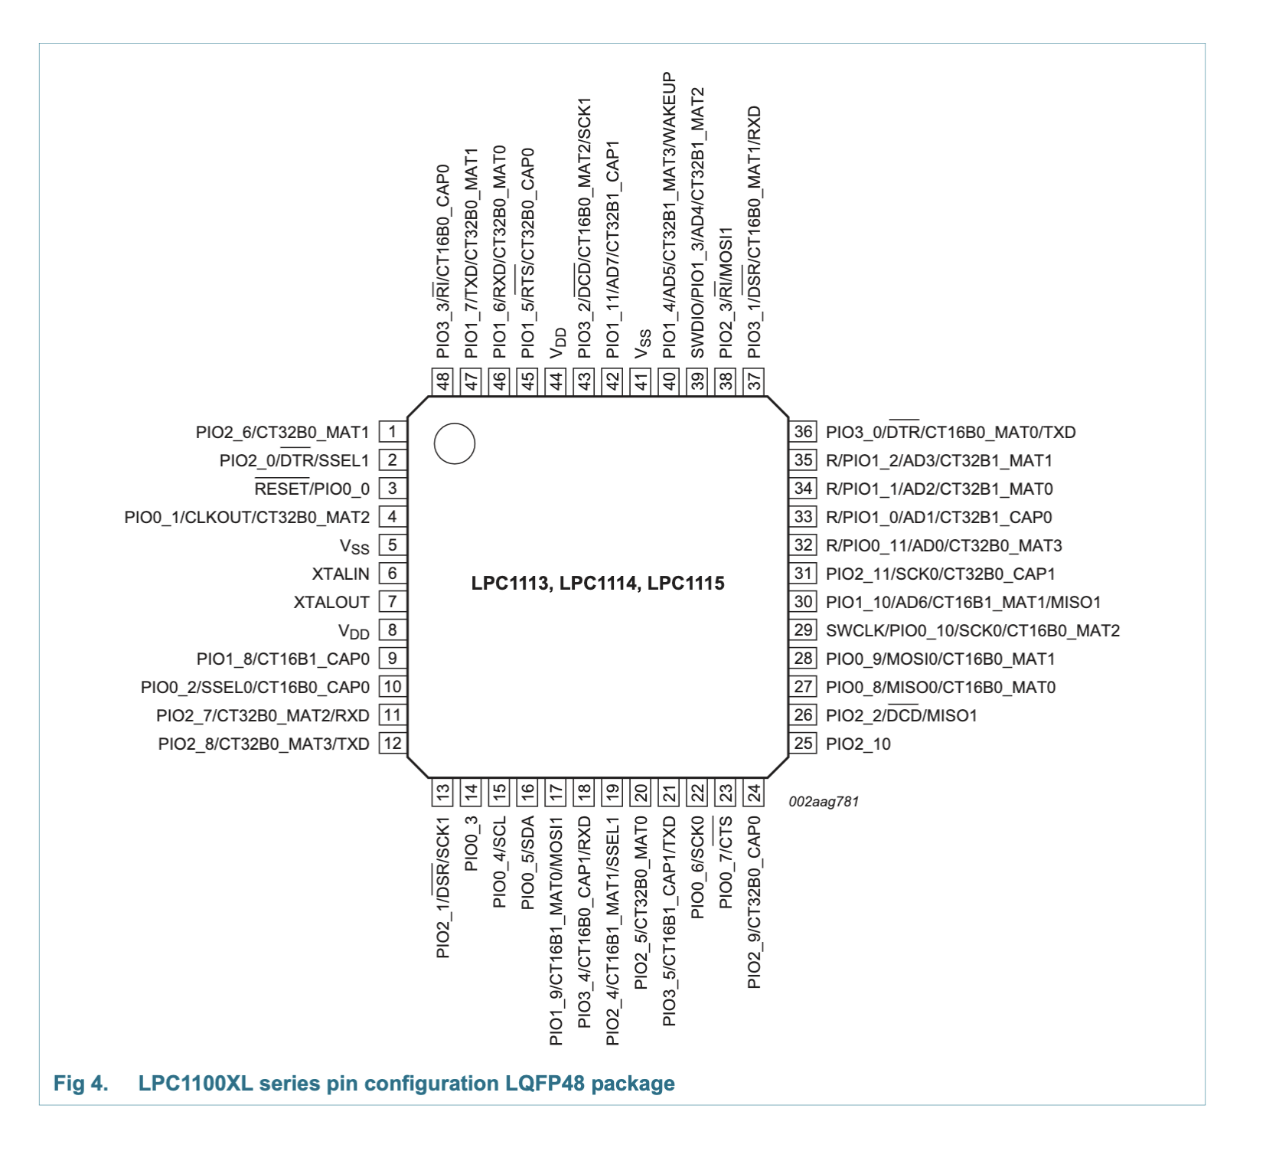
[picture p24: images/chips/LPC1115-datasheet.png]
Datasheet diagram
|  |  |

## Toshiba TB62269FTG Driver

A two-phase bipolar stepping motor driver using a PWM chopper. It can run on **full, 1/2, 1/4, 1/8, 1/16, and 1/32 steps**.

Refer to the [Toshiba TB62269FTG Datasheet](../SOURCES.md#datasheet-toshiba-tb62269ftg) for more information.

### Pinout

Per-chip connections: [steppers.md](pinouts/steppers.md)

General pinout: [tb62269ftg-pinout.md](pinouts/tb62269ftg-pinout.md)

### Photos

| 48 Pin WQFN package TB62269FTG chip from top-view. First pin starts on the left of the bottom side, and goes counterclockwise. | Datasheet diagram with the first pin on the left of the bottom side. |
| --- | --- |
| Top view | Datasheet diagram |

## Macronix MX25L3206E Flash Memory

A 32 Mbit (4MB) CMOS serial NOR flash chip with a Serial Peripheral Interface (3-wire bus: clock, serial data in, serial data out), usable in single or dual output mode.

It has:

- **SPI connection** with a max clock speed of 86MHz (80MHz in Dual Output mode)

Refer to the [Macronix MX25L3206E Datasheet](../SOURCES.md#datasheet-macronix-mx25l3206e) for more information.

### Pinout

| Pin | Name | Description | MCU  | Verified? |
| --- | --- | --- | ---- | --- |
| 01  | CS# | Chip Select | | ❌ |
| 02  | SI/SIO0 | Serial Data Input | | ❌ |
| 03  | SO/SIO1 | Serial Data Output | | ❌ |
| 04  | SCLK | Clock Input | | ❌ |
| 05  | WP# | Write protection | | ❌ |
| 06  | HOLD# | Hold, to pause the device | | ❌ |
| 07  | VCC | + 3.3V Power Supply | 3.3V | ❌ |
| 08  | GND | Ground | GND  | ❌ |

### Photos

| 8 Pin SOP package MX25L3206E chip from top-view. First pin starts on top of the left side, and goes counterclockwise. | Datasheet diagram with the first pin on top of the left side.  |
| --- | --- |
| Top view | Datasheet diagram |

## AC-1203D RP1 Buzzer

Despite not being a critical component, it was fitting to put it here.

Refer to the [AATC AC-1203D RP1 Datasheet](https://aatc.tw/mouser_2025/AC-1203D-RP1.pdf) for more information.

### Pinout

| Pin | Name | Description | MCU | Verified? |
| --- | ---- | --- | --- | --- |
| 01  | | | | ❌ |

### Photos

| Top view of the buzzer                             |
| -------------------------------------------------- |
| Top view |

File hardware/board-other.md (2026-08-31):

# Other Hardware

The remaining components that do not belong to a board, but are important for the project are documented here.

There are 4 steppers, 3 endstops, 1 filament sensor on the extruder motor, and another on the hotend.

**Current known components:**

- [Stepper Motors](steppers.md)
- [Sensors](sensors.md)
- [RFID reader](rfid-reader.md)
- Top light bar
- Reflow fan

Top light bar connects to **pin PD23**. It is active-high.

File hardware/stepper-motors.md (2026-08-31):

# Stepper Motors

They seem to be Nema 17's. There are 4 of them, one for each axis (X, Y, Z, and E).

## Pinout

| Pin Name  | Driver | MCU | Pin Desc | Verified? |
| --- | --- | --- | --- | --- |
| X Enable  | U10 3 ENABLE  | 128 | PD3 | ✅ |
| X Step | U10 2 CLK_IN  | 127 | PC23 | ✅ |
| X Dir | U10 44 CW/CCW | 126 | PD4 | ✅ |
| Y Enable  | U11 3 ENABLE  | 125 | PD5 | ✅ |
| Y Step | U11 2 CLK_IN  | 124 | PC22 | ✅ |
| Y Dir | U11 44 CW/CCW | 7 | PE2 | ✅ |
| Z Enable  | U12 3 ENABLE  | 121 | PD6 | ✅ |
| Z Step | U12 2 CLK_IN  | 120 | PC20 | ✅ |
| Z Dir | U12 44 CW/CCW | 119 | PD7 | ✅ |
| E1 Enable | U14 3 ENABLE  | 78  | PD16 | ✅ |
| E1 Step | U14 2 CLK_IN  | 76  | PC28 | ✅ |
| E1 Dir | U14 44 CW/CCW | 74  | PD17 | ✅ |

My other findings:

- Drivers are enabled on Enable High
- Drivers are CW on Dir High
- X driver does a full rotation on 3200 steps
- Y driver does a full rotation on 3200 steps
- Z driver does a full rotation on 6400 steps (maybe we can increase the resolution of other motors too?)
- E driver does a full rotation on 3200 steps

## Photos

| In this photo the one on the left is E1, the one in the back is Z, and the other two are Y and X. Y and X seem to have the same head. | X motor is on the left side and moves along the Z axis, and stays parallel to the print bed. |
| --- | --- |
| All steppers after removal (YT) | Back view (YT) |

| Y motor sits in the middle of the print bed, slightly to the right. It's fixed in the place, and sits perpendicular to the print bed. | Z motor sits parallel to the Y motor, and is also fixed in the place. |
| --- | --- |
| Back view (YT) | Back view (YT) |

| E motor sits on the top left side and is perpendicular to the print bed, is fixed in place. | E motor from the side view. |
| --- | --- |
| Front view (YT) | Side view (YT) |

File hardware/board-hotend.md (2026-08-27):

# Hotend

The hotend components are mostly standard, with an extra flash chip for hotend identification.

- 1x Heater
- 1x NTC
- 1x Fan
- 1x Filament sensor (?)
- 1x Atmel AT24C02D Flash Memory

## Atmel AT24C02D Flash Memory

Refer to the [Atmel AT24C01D/AT24C02D Flash Memory Datasheet](https://ww1.microchip.com/downloads/en/DeviceDoc/AT24C01D-AT24C02D-I2C-Compatible-Two-Wire-Serial-EEPROM-1Kbit-2Kbit-20006100A.pdf) datasheet for more information.

### Photos

| 8 Pin SOIC package AT24C02D chip from top-view. First pin starts on the left of the bottom side, and goes counterclockwise. | Datasheet diagram with the first pin on top of the left side. |
| --- | --- |
| Top View | Datasheet diagram  |

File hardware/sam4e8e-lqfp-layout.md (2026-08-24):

## SAM4E 144-lead LQFP Pinout

| MCU | Pin Desc | MCU | Pin Desc | MCU | Pin Desc | MCU | Pin Desc |
| --- | --- | --- | --- | --- | --- | --- | --- |
| 1 | PD0 | 37  | PA22/PGMD10 | 73  | PA5/PGMRDY  | 109 | PB5 |
| 2 | PD31 | 38  | PC1 | 74  | PD17 | 110 | PD9 |
| 3 | VDDOUT | 39  | PC2 | 75  | PA9/PGMM1 | 111 | PC18 |
| 4 | PE0 | 40  | PC3 | 76  | PC28 | 112 | PA28 |
| 5 | VDDIN | 41  | PC4 | 77  | PA4/PGMNCMD | 113 | PD8 |
| 6 | PE1 | 42  | PA13/PGMD1  | 78  | PD16 | 114 | PA6/PGMNOE |
| 7 | PE2 | 43  | VDDIO | 79  | PB6 | 115 | GND |
| 8 | GND | 44  | GND | 80  | VDDIO | 116 | PA30 |
| 9 | ADVREFP | 45  | PA16/PGMD4  | 81  | VDDCORE | 117 | PC19 |
| 10  | PE3 | 46  | PA23/PGMD11 | 82  | PC8 | 118 | PA31 |
| 11  | PC0 | 47  | PD27 | 83  | NRST | 119 | PD7 |
| 12  | PC27 | 48  | PC7 | 84  | PD14 | 120 | PC20 |
| 13  | PC26 | 49  | PA15/PGMD3  | 85  | TEST | 121 | PD6 |
| 14  | PC31 | 50  | VDDCORE | 86  | PC9 | 122 | PC21 |
| 15  | PC30 | 51  | PA14/PGMD2  | 87  | PB12 | 123 | VDDCORE |
| 16  | PC29 | 52  | PD25 | 88  | PD13 | 124 | PC22 |
| 17  | PC12 | 53  | PD26 | 89  | PB7 | 125 | PD5 |
| 18  | PC15 | 54  | PC6 | 90  | PC10 | 126 | PD4 |
| 19  | PC13 | 55  | PD24 | 91  | PA3 | 127 | PC23 |
| 20  | PB1 | 56  | PA24/PGMD12 | 92  | PD12 | 128 | PD3 |
| 21  | PB0 | 57  | PD23 | 93  | PA2 | 129 | PA29 |
| 22  | PA20/PGMD8 | 58  | PC5 | 94  | PC11 | 130 | PC24 |
| 23  | PA19/PGMD7 | 59  | PA25/PGMD13 | 95  | GND | 131 | PD2 |
| 24  | PA18/PGMD6 | 60  | PD22 | 96  | VDDIO | 132 | PD1 |
| 25  | PA17/PGMD5 | 61  | GND | 97  | PC14 | 133 | PC25 |
| 26  | PB2 | 62  | PA26/PGMD14 | 98  | PD11 | 134 | VDDIO |
| 27  | PE4 | 63  | PD21 | 99  | PA1/PGMEN1  | 135 | GND |
| 28  | PE5 | 64  | PA11/PGMM3  | 100 | PC16 | 136 | PB10 |
| 29  | VDDCORE | 65  | PD20 | 101 | PD10 | 137 | PB11 |
| 30  | VDDIO | 66  | PA10/PGMM2  | 102 | PA0/PGMEN0  | 138 | GND |
| 31  | PB3 | 67  | PD19 | 103 | PC17 | 139 | VDDPLL |
| 32  | PA21/PGMD9 | 68  | PA12/PGMD0  | 104 | JTAGSEL | 140 | PB14 |
| 33  | VDDCORE | 69  | PD18 | 105 | PB4 | 141 | PB8 |
| 34  | PD30 | 70  | PA27/PGMD15 | 106 | PD15 | 142 | PB9 |
| 35  | PA7/PGMNVALID | 71  | PD28 | 107 | VDDCORE | 143 | VDDIO |
| 36  | PA8/PGMM0 | 72  | VDDIO | 108 | PD29 | 144 | PB13 |

- Source: [Atmel SAM4E Datasheet](https://ww1.microchip.com/downloads/aemDocuments/documents/OTH/ProductDocuments/DataSheets/Atmel-11157-32-bit-Cortex-M4-Microcontroller-SAM4E16-SAM4E8_Datasheet.pdf)

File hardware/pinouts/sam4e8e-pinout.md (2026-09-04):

# SAM4E 144-lead LQFP Pinout

> **Traced** means the pin is traced on the PCB to both ends and at least verified multiple times (3+), or at least twice with a multimeter. **Verified** means the pin is verified to trigger the correct i/o on software.
>
> The pins marked as "?" are the ones that are connected to something, but havent been traced yet.
> The pins marked as "-" are the ones that do not have a VISIBLE connection. It does NOT mean the pin is not connected, as the chip has multiple connections going under it.

Due to the chip size, I have separated the pinout into four sections for easier readability and traceability.

## Side 1

| Pin | Pin Desc | Connected To | Description | Traced? | Verified? |
| --- | --- | --- | --- | --- | --- |
| 01  | PD0 | ? | Unknown | ❌ | ❌ |
| 02  | PD31 | ? | Unknown | ❌ | ❌ |
| 03  | VDDOUT | ? | Unknown | ❌ | ❌ |
| 04  | PE0 | ? | Unknown | ❌ | ❌ |
| 05  | VDDIN | ? | Unknown | ❌ | ❌ |
| 06  | PE1 | ? | Unknown | ❌ | ❌ |
| 07  | PE2 | - | Not connected | ❌ | ❌ |
| 08  | GND | ? | Unknown | ❌ | ❌ |
| 09  | ADVREFP | ? | Unknown | ❌ | ❌ |
| 10  | PE3 | - | Not connected | ❌ | ❌ |
| 11  | PC0 | - | Not connected | ❌ | ❌ |
| 12  | PC27 | ? | Unknown | ❌ | ❌ |
| 13  | PC26 | - | Not connected | ❌ | ❌ |
| 14  | PC31 | ? | Unknown | ❌ | ❌ |
| 15  | PC30 | ? | Unknown | ❌ | ❌ |
| 16  | PC29 | ? | Unknown | ❌ | ❌ |
| 17  | PC12 | ? | Unknown | ❌ | ❌ |
| 18  | PC15 | ? | Unknown | ❌ | ❌ |
| 19  | PC13 | ? | Unknown | ❌ | ❌ |
| 20  | PB1 | - | Not connected | ❌ | ❌ |
| 21  | PB0 | - | Not connected | ❌ | ❌ |
| 22  | PA20/PGMD8 | ? | Unknown | ❌ | ❌ |
| 23  | PA19/PGMD7 | ? | Unknown | ❌ | ❌ |
| 24  | PA18/PGMD6 | ? | Unknown | ❌ | ❌ |
| 25  | PA17/PGMD5 | - | Not connected | ❌ | ❌ |
| 26  | PB2 | - | Not connected | ❌ | ❌ |
| 27  | PE4 | - | Not connected | ❌ | ❌ |
| 28  | PE5 | ? | Unknown | ❌ | ❌ |
| 29  | VDDCORE | ? | Unknown | ❌ | ❌ |
| 30  | VDDIO | 3.3V | 3.3V Power | ✅ | ❌ |
| 31  | PB3 | - | Not connected | ❌ | ❌ |
| 32  | PA21/PGMD9 | - | Not connected | ❌ | ❌ |
| 33  | VDDCORE | ? | Unknown | ❌ | ❌ |
| 34  | PD30 | - | Not connected | ❌ | ❌ |
| 35  | PA7/XIN32  | Y2 1 XTAL1 | 32kHz Crystal | ✅ | ❌ |
| 36  | PA8/XOUT32 | Y2 2 XTAL2 | 32kHz Crystal | ✅ | ❌ |

## Side 2

| Pin | Pin Desc | Connected To | Description | Traced? | Verified? |
| --- | --- | --- | --- | --- | --- |
| 37  | PA22/PGMD10 | - | Not connected | ❌ | ❌ |
| 38  | PC1 | - | Not connected | ❌ | ❌ |
| 39  | PC2 | - | Not connected | ❌ | ❌ |
| 40  | PC3 | - | Not connected | ❌ | ❌ |
| 41  | PC4 | - | Not connected | ❌ | ❌ |
| 42  | PA13/PGMD1  | - | Not connected | ❌ | ❌ |
| 43  | VDDIO | 3.3V | 3.3V Power | ✅ | ❌ |
| 44  | GND | ? | Unknown | ❌ | ❌ |
| 45  | PA16/PGMD4  | - | Not connected | ❌ | ❌ |
| 46  | PA23/PGMD11 | ? | Unknown | ❌ | ❌ |
| 47  | PD27 | - | Not connected | ❌ | ❌ |
| 48  | PC7 | - | Not connected | ❌ | ❌ |
| 49  | PA15/PGMD3  | ? | Unknown | ❌ | ❌ |
| 50  | VDDCORE | ? | Unknown | ❌ | ❌ |
| 51  | PA14/PGMD2  | - | Not connected | ❌ | ❌ |
| 52  | PD25 | ? | Unknown | ❌ | ❌ |
| 53  | PD26 | ? | Unknown | ❌ | ❌ |
| 54  | PC6 | - | Not connected | ❌ | ❌ |
| 55  | PD24 | - | Not connected | ❌ | ❌ |
| 56  | PA24/PGMD12 | - | Not connected | ❌ | ❌ |
| 57  | PD23 | J5 1 ? | Top lamp | ❌ | ✅ |
| 58  | PC5 | - | Not connected | ❌ | ❌ |
| 59  | PA25/PGMD13 | - | Not connected | ❌ | ❌ |
| 60  | PD22 | ? | Unknown | ❌ | ❌ |
| 61  | GND | ? | Unknown | ❌ | ❌ |
| 62  | PA26/PGMD14 | - | Not connected | ❌ | ❌ |
| 63  | PD21 | ? | Unknown | ❌ | ❌ |
| 64  | PA11/PGMM3  | - | Not connected | ❌ | ❌ |
| 65  | PD20 | ? | Unknown | ❌ | ❌ |
| 66  | PA10/PGMM2  | ? | Unknown | ❌ | ❌ |
| 67  | PD19 | J37 ? ? | Z endstop | ❌ | ❌ |
| 68  | PA12/PGMD0  | - | Not connected | ❌ | ❌ |
| 69  | PD18 | ? | Unknown | ❌ | ❌ |
| 70  | PA27/PGMD15 | - | Not connected | ❌ | ❌ |
| 71  | PD28 | ? | Unknown | ❌ | ❌ |
| 72  | VDDIO | 3.3V | 3.3V Power | ✅ | ❌ |

## Side 3

| Pin | Pin Desc | Connected To  | Description | Traced? | Verified? |
| --- | --- | --- | --- | --- | --- |
| 73  | PA5/PGMRDY  | - | Not connected | ❌ | ❌ |
| 74  | PD17 | U14 44 CW/CCW | E1 motor dir | ❌ | ✅ |
| 75  | PA9/PGMM1 | ? | Unknown | ❌ | ❌ |
| 76  | PC28 | U14 2 CLK_IN  | E1 motor step | ❌ | ✅ |
| 77  | PA4/PGMNCMD | - | Not connected | ❌ | ❌ |
| 78  | PD16 | U14 3 ENABLE  | E1 motor enable | ❌ | ✅ |
| 79  | PB6 | ? | Unknown | ❌ | ❌ |
| 80  | VDDIO | ? | Unknown | ❌ | ❌ |
| 81  | VDDCORE | ? | Unknown | ❌ | ❌ |
| 82  | PC8 | - | Not connected | ❌ | ❌ |
| 83  | NRST | ? | Unknown | ❌ | ❌ |
| 84  | PD14 | - | Not connected | ❌ | ❌ |
| 85  | TEST | ? | Unknown | ❌ | ❌ |
| 86  | PC9 | - | Not connected | ❌ | ❌ |
| 87  | PB12 | ? | Unknown | ❌ | ❌ |
| 88  | PD13 | - | Not connected | ❌ | ❌ |
| 89  | PB7 | ? | Unknown | ❌ | ❌ |
| 90  | PC10 | - | Not connected | ❌ | ❌ |
| 91  | PA3 | - | Not connected | ❌ | ❌ |
| 92  | PD12 | ? | Unknown | ❌ | ❌ |
| 93  | PA2 | - | Not connected | ❌ | ❌ |
| 94  | PC11 | ? | Unknown | ❌ | ❌ |
| 95  | GND | ? | Unknown | ❌ | ❌ |
| 96  | VDDIO | ? | Unknown | ❌ | ❌ |
| 97  | PC14 | ? | Unknown | ❌ | ❌ |
| 98  | PD11 | - | Not connected | ❌ | ❌ |
| 99  | PA1/PGMEN1  | ? | Unknown | ❌ | ❌ |
| 100 | PC16 | ? | Unknown | ❌ | ❌ |
| 101 | PD10 | ? | Unknown | ❌ | ❌ |
| 102 | PA0/PGMEN0  | ? | Unknown | ❌ | ❌ |
| 103 | PC17 | ? | Unknown | ❌ | ❌ |
| 104 | JTAGSEL | ? | Unknown | ❌ | ❌ |
| 105 | PB4 | ? | Unknown | ❌ | ❌ |
| 106 | PD15 | ? | Unknown | ❌ | ❌ |
| 107 | VDDCORE | ? | Unknown | ❌ | ❌ |
| 108 | PD29 | ? | Unknown | ❌ | ❌ |

## Side 4

| Pin | Pin Desc | Connected To  | Description | Traced? | Verified? |
| --- | --- | --- | --- | --- | --- |
| 109 | PB5 | ? | Unknown | ❌ | ❌ |
| 110 | PD9 | J37 ? ? | Y endstop | ❌ | ❌ |
| 111 | PC18 | - | Not connected  | ❌ | ❌ |
| 112 | PA28 | - | Not connected  | ❌ | ❌ |
| 113 | PD8 | J37 ? ? | X endstop | ❌ | ❌ |
| 114 | PA6/PGMNOE | - | Not connected  | ❌ | ❌ |
| 115 | GND | - | Not connected  | ❌ | ❌ |
| 116 | PA30 | - | Not connected  | ❌ | ❌ |
| 117 | PC19 | ? | Unknown | ❌ | ❌ |
| 118 | PA31 | - | Not connected  | ❌ | ❌ |
| 119 | PD7 | U12 44 CW/CCW | Z motor dir | ❌ | ✅ |
| 120 | PC20 | U12 2 CLK_IN  | Z motor step | ❌ | ✅ |
| 121 | PD6 | U12 3 ENABLE  | Z motor enable | ❌ | ✅ |
| 122 | PC21 | ? | Unknown | ❌ | ❌ |
| 123 | VDDCORE | ? | Unknown | ❌ | ❌ |
| 124 | PC22 | U11 2 CLK_IN  | Y motor step | ❌ | ✅ |
| 125 | PD5 | U11 3 ENABLE  | Y motor enable | ❌ | ✅ |
| 126 | PD4 | U10 44 CW/CCW | X motor dir | ❌ | ✅ |
| 127 | PC23 | U10 2 CLK_IN  | X motor step | ❌ | ✅ |
| 128 | PD3 | U10 3 ENABLE  | X motor enable | ❌ | ✅ |
| 129 | PA29 | - | Not connected  | ❌ | ❌ |
| 130 | PC24 | - | Not connected  | ❌ | ❌ |
| 131 | PD2 | - | Not connected  | ❌ | ❌ |
| 132 | PD1 | - | Not connected  | ❌ | ❌ |
| 133 | PC25 | - | Not connected  | ❌ | ❌ |
| 134 | VDDIO | ? | Unknown | ❌ | ❌ |
| 135 | GND | ? | Unknown | ❌ | ❌ |
| 136 | PB10 | ? | Unknown | ❌ | ❌ |
| 137 | PB11 | ? | Unknown | ❌ | ❌ |
| 138 | GND | ? | Unknown | ❌ | ❌ |
| 139 | VDDPLL | ? | Unknown | ❌ | ❌ |
| 140 | PB14 | - | Not connected  | ❌ | ❌ |
| 141 | PB8/XOUT | Y1 1 XTAL1 | 12MHz Crystal  | ✅ | ❌ |
| 142 | PB9/XIN | Y1 2 XTAL2 | 12MHz Crystal  | ✅ | ❌ |
| 143 | VDDIO | 3.3V | 3.3V Power | ✅ | ❌ |
| 144 | PB13 | ? | Unknown | ❌ | ❌ |

- Pin Source: [Atmel SAM4E Datasheet](../../SOURCES.md#datasheet-atmel-sam4e8e)

# New pinout

I have decided to list pins by PIO and not by MCU pin, since most of them are useless for our use case.

We have 5 PIOs available, PA through PE.

- PIO A: 32 pins (PA0 through PA31)
- PIO B: 15 pins (PB0 through PB14)
- PIO C: 32 pins (PC0 through PC31)
- PIO D: 32 pins (PD0 through PD31)
- PIO E: 6 pins (PE0 through PE5)

## PIO A

| Pin  | Connected to | Description | Traced? | Verified? |
| ---- | --- | --- | --- | --- |
| PA0  | | | ❌ | ❌ |
| PA1  | | | ❌ | ❌ |
| PA2  | | | ❌ | ❌ |
| PA3  | | | ❌ | ❌ |
| PA4  | | | ❌ | ❌ |
| PA5  | | | ❌ | ❌ |
| PA6  | | | ❌ | ❌ |
| PA7  | | | ❌ | ❌ |
| PA8  | | | ❌ | ❌ |
| PA9  | | | ❌ | ❌ |
| PA10 | | | ❌ | ❌ |
| PA11 | | | ❌ | ❌ |
| PA12 | | | ❌ | ❌ |
| PA13 | | | ❌ | ❌ |
| PA14 | | | ❌ | ❌ |
| PA15 | | | ❌ | ❌ |
| PA16 | | | ❌ | ❌ |
| PA17 | SW5 | Enter btn | ❌ | ✅ |
| PA18 | | | ❌ | ❌ |
| PA19 | | | ❌ | ❌ |
| PA20 | | | ❌ | ❌ |
| PA21 | SW2 | Down btn | ❌ | ✅ |
| PA22 | | | ❌ | ❌ |
| PA23 | | | ❌ | ❌ |
| PA24 | | | ❌ | ❌ |
| PA25 | SD CD | Card detect | ❌ | ✅ |
| PA26 | SD DAT2 | - | ❌ | ✅ |
| PA27 | SD CS/DAT3 | CS | ❌ | ✅ |
| PA28 | SD CMD | MOSI | ❌ | ✅ |
| PA29 | SD CLK | SCK | ❌ | ✅ |
| PA30 | SD DAT0 | MISO | ❌ | ✅ |
| PA31 | SD DAT1 | - | ❌ | ✅ |

## PIO B

| Pin  | Connected to | Description | Traced? | Verified? |
| ---- | --- | --- | --- | --- |
| PB0  | | | | |
| PB1  | | | | |
| PB2  | | | | |
| PB3  | SW4 | Left btn | ❌ | ✅ |
| PB4  | | | | |
| PB5  | | | | |
| PB6  | | | | |
| PB7  | | | | |
| PB8  | | | | |
| PB9  | | | | |
| PB10 | | | | |
| PB11 | | | | |
| PB12 | | | | |
| PB13 | | | | |
| PB14 | | | | |

## PIO C

| Pin  | Connected to | Description | Traced? | Verified? |
| ---- | --- | --- | --- | --- |
| PC0  | | | | |
| PC1  | | | | |
| PC2  | | | | |
| PC3  | | | | |
| PC4  | | | | |
| PC5  | | | | |
| PC6  | | | | |
| PC7  | | | | |
| PC8  | | | | |
| PC9  | | | | |
| PC10 | | | | |
| PC11 | | | | |
| PC12 | | | | |
| PC13 | | | | |
| PC14 | | | | |
| PC15 | | | | |
| PC16 | | | | |
| PC17 | | | | |
| PC18 | | | | |
| PC19 | Y endstop | Y endstop | ❌ | ✅ |
| PC20 | Z step | Z step | ❌ | ✅ |
| PC21 | | | | |
| PC22 | Y step | Y step | ❌ | ✅ |
| PC23 | X step | X step | ❌ | ✅ |
| PC24 | | | | |
| PC25 | | | | |
| PC26 | | | | |
| PC27 | | | | |
| PC28 | E1 step | E1 step | ❌ | ✅ |
| PC29 | | | | |
| PC30 | | | | |
| PC31 | | | | |

## PIO D

| Pin  | Connected to | Description | Traced? | Verified? |
| ---- | --- | --- | --- | --- |
| PD0  | | | | |
| PD1  | | | | |
| PD2  | | | | |
| PD3  | X enable | X enable | ❌ | ✅ |
| PD4  | X dir | X dir | ❌ | ✅ |
| PD5  | Y enable | Y enable | ❌ | ✅ |
| PD6  | Z enable | Z enable | ❌ | ✅ |
| PD7  | Z dir | Z dir | ❌ | ✅ |
| PD8  | X endstop | X endstop | ❌ | ✅ |
| PD9  | Z endstop | Z endstop | ❌ | ✅ |
| PD10 | | | | |
| PD11 | | | | |
| PD12 | | | | |
| PD13 | | | | |
| PD14 | | | | |
| PD15 | | | | |
| PD16 | E1 enable | E1 enable | ❌ | ✅ |
| PD17 | E1 dir | E1 dir | ❌ | ✅ |
| PD18 | | | | |
| PD19 | | | | |
| PD20 | | | | |
| PD21 | | | | |
| PD22 | | | | |
| PD23 | | | | |
| PD24 | | | | |
| PD25 | | | | |
| PD26 | | | | |
| PD27 | | | | |
| PD28 | | | | |
| PD29 | | | | |
| PD30 | SW6 | Home btn | ❌ | ✅ |
| PD31 | | | | |

## PIO E

| Pin | Connected to | Description | Traced? | Verified? |
| --- | --- | --- | --- | --- |
| PE0 | | | | |
| PE1 | SW1 | Up btn | ❌ | ✅ |
| PE2 | Y dir | Y dir | ❌ | ✅ |
| PE3 | | | | |
| PE4 | SW3 | Right btn | ❌ | ✅ |
| PE5 | | | | |

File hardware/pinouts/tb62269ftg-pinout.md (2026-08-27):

# TB62269FTG 48-Lead WQFN Pinout

| Pin | Pin Name | Description | Pin | Pin Name | Description |
| --- | --- | --- | --- | --- | --- |
| 01  | NC | No-connect | 25  | NC | No-connect |
| 02  | CLK_IN | Clock input, important for motor frequency | 26  | OUT_B2* | Bch positive driver output |
| 03  | ENABLE | A/B channel output enable | 27  | OUT_B1* |
| 04  | RESET | Electric angle reset | 28  | NC | No-connect |
| 05  | GND | Logic ground | 29  | RS_B2* | Motor Bch current sense pin |
| 06  | NC | No-connect | 30  | RS_B1* | |
| 07  | RS_A1* | Motor Ach current sense pin | 31  | NC | No-connect |
| 08  | RS_A2* | 32 | VM  | Motor Power supply |
| 09  | NC | No-connect | 33  | NC | No-connect |
| 10  | OUT_A1*  | Ach positive driver output | 34  | VCC | Internal VCC regulator monitor pin |
| 11  | OUT_A2*  | 35 | NC  | No-connect |
| 12  | NC | No-connect | 36  | NC | No-connect |
| 13  | NC | No-connect | 37  | NC | No-connect |
| 14  | NC | No-connect | 38  | L_OUT | Error detect signal output |
| 15  | GND | Motor power ground | 39  | D_MODE0 | Step resolution mode control 0 |
| 16  | OUT_A1-* | Ach negative driver output | 40  | GND | Logic ground |
| 17  | OUT_A2-* | Ach negative driver output | 41  | VREF_B | Tunes the current level for Bch motor drive. |
| 18  | GND | Motor power ground | 42  | VREF_A | Tunes the current level for Ach motor drive. |
| 19  | GND | Motor power ground | 43  | OSCM | Oscillator pin for PWM chopper |
| 20  | OUT_B2-* | Bch negative driver output | 44  | CW/CCW | Motor rotation: forward/reverse |
| 21  | OUT_B1-* | Bch negative driver output | 45  | MO_OUT | Electric angle monitor |
| 22  | GND | Motor power ground | 46  | D_MODE1 | Step resolution mode control 1 |
| 23  | NC | No-connect | 47  | D_MODE2 | Step resolution mode control 2 |
| 24  | NC | No-connect | 48  | NC | No-connect |

- Source: [Toshiba TB62269FTG Datasheet](../../SOURCES.md#datasheet-toshiba-tb62269ftg)

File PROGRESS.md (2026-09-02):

## Current progress

I have dumped the firmware of the 2. mpu, but i now need to trace all the pins and cables to the mpu's and connectors to be able to continue at all. the problem is, my multimeter is dead and im stuck unable to measure anything, aka not being able to continue at all.

Will continue when i figure out a way to power the multimeter.

Until then i will continue by fixing the broken links and update the docs.

### Update 26.08.2026 13:30 GMT+3:

I got a battery and now im back in business!
Going to trace the sub board first as it is the easiest to trace so far

### Update 26.08.2026 15:00 GMT+3:

I need a better way to note my pins. Having them spread out makes it A LOT harder to keep track of them.

I have decided to desolder the LCM since i cant trace cables under it easily. Ill probably end up breaking something but idonno

### Update 26.08.2026 18:45 GMT+3:

I have finished tracing the sub board and drawing the KiCAD schematic. I am tired and going to continue tonight/tomorrow.

### Update 27.08.2026 04:40 GMT+3:

I drew the hotend board and almost finished it, and started working on the main board drawings. At the same time im also cleaning up the repo structure. Its too lonely working like this but somehow i dont feel it

Tomorrow i will continue on working on the secondary MCU and its dumped firmware.

### Update 27.08.2026 14:30 GMT+3:

I will proceed by decompiling the secondary mcu firmware.

### Update 28.08.2026 18:54 GMT+3:

I decompiled the secondary mcu firmware, but im realizing i first need to have some idea on which pins might be for what functions.

### Update 31.08.2026 19:00 GMT+3:

I stopped decompiling work, and continued with pinout tracing. So far we have all the essential pins traced (including buttons/lcd/sd), but i want to trace everything before creating a schematic. The LPC MCU is also easily flashable via UART and SWD, which will make things easier.

### Update 31.08.2026 20:00 GMT+3:

Due to the split MCU design, klipper support looks hard without hardware modding. I will continue by searching about RRF instead.

### Update 31.08.2026 23:20 GMT+3:

I need to fork RRF since the dual mcu stuff, and write custom firmware for the LPC chip and manage it over uart.

### Update 01.09.2026 00:57 GMT+3:

Figured out there are fuses on the main board. There were 2 separate 12v lanes and i was confused. first one is unfused, goes to the motor drivers current sense pin? weird. Other one is fused, goes to motors. there is also a hotend heater fuse, but its separate.

There are 4 fuses so far from what i can tell. One for heater, one for reflow fan (maybe mine is popped?) one for motors inputs.

This fixed me being stuck about the schematics, as i did not know what was some of the main power lanes were connected to. Now i got a bigger problem about marking power lanes or drawing them all fully. ig ill end up drawing them all and only labeling the raw one as 12v.

Update: okay they are all fused, i was just blind. on a side note, all my fuses seem to be intact.

### Update 01.09.2026 22:00 GMT+3:

Its getting tiring to trace everything manually on the main board since its too big to keep track of, especially since the high amount of vias. I keep losing track of which pin goes where, especially power pins, which makes it look like stuff are getting power from some divine place or something, i cant find the source of the power. I will continue tracing by creating a serial firmware to poke at the pins. For now ill do something basic that prints the triggered pins to serial, in the future i can make some firmata style interface or a firmata fork for it if i need to.

### Update 02.09.2026 13:00 GMT+3:

I checked the klipper source, firmata source and RRF source and decided to take the klipper gpio and uart code, take their linker and compiling scripts, gut klipper specific stuff from them and implement firmata on it. It will take a while probably since im not too familiar with raw C toolchain and their flags.

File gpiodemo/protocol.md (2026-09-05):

# GPIO wire protocol

The GPIO controller uses newline-delimited ASCII packets. The desktop host sends requests and firmware nodes send responses. Every packet begins with a request ID and a route token.

## Framing and packet IDs

Each packet is one ASCII line terminated by `\n`. Receivers can ignore `\r` while assembling a line. A packet must fit within the protocol's 64-byte maximum frame size, including its newline terminator.

The host allocates request IDs from `001` through `999`. IDs are decimal, and the host renders them as three digits on the wire. After `999`, allocation wraps to `001`. The host must not reuse an ID while a request with that ID is still outstanding. Firmware preserves the host's ID in every response and listener event. Intermediate devices do not allocate or translate IDs.

Most requests finish after one response. Grouped requests and `MAP` finish at their terminal `OKA`. A successful `LSN ... ON` keeps its request ID alive for later `HYG` listener events until listening is stopped, replaced, or reset.

## Packet envelopes

Requests have this form:

```text
<id> <destination> <command...>
```

Responses have this form:

```text
<id> <source> <response...>
```

For example:

```text
001 SAM HAI
001 SAM HII <3
```

`destination` and `source` are protocol-name tokens such as `SAM`, `LPC`, or another configured name. They are not a closed list defined by the protocol. A token is non-empty and contains no whitespace or control characters.

The current PC-connected node is named `SAM`.

## Targets

GPIO commands that take a target accept one of three forms:

| Form | Example | Meaning |
| --- | --- | --- |
| Pin | `PA00` | One GPIO pin |
| Bank | `PIOA` | One GPIO bank |
| All | `ALL` | Every exposed GPIO pin |

The current SAM node exposes these native names:

- `PA00` through `PA31` in `PIOA`.
- `PB00` through `PB14` in `PIOB`.
- `PC00` through `PC31` in `PIOC`.
- `PD00` through `PD31` in `PIOD`.
- `PE00` through `PE05` in `PIOE`.

Numeric GPIO IDs are not valid targets. UART1 reserves SAM pins PA05 and PA06 for the LPC link. The board/USB path reserves PB08 through PB11. These pins report `UNAVAILABLE` for individual GPIO operations. Grouped operations skip unavailable pins.

Pins begin in the `UNSET` state. `DIR` initializes a pin. Commands whose meaning depends on an initialized direction do not implicitly initialize it.

## Requests

| Command | Form | Meaning |
| --- | --- | --- |
| Hello | `HAI` | Check that the addressed node is responding. |
| Status | `HRU` | Ask the node to identify itself. |
| Map | `MAP` | Stream the addressed node's GPIO bank and pin metadata. |
| Direction | `DIR <target> IN OK?` / `DIR <target> OUT OK?` | Configure input or output direction. |
| Read | `GET <target> OK?` | Read initialized pins in the selected scope. |
| Write | `SET <target> LOW OK?` / `SET <target> HIGH OK?` | Drive initialized output pins. |
| Pull-up | `PLL <target> OFF OK?` / `PLL <target> ON OK?` | Turn input pull-up off or on. |
| Listen | `LSN <target> OFF OK?` / `LSN <target> ON OK?` | Stop or start change notifications. |
| Query | `WYD <target> DIR` / `WYD <target> PLL` / `WYD <target> LSN` | Query direction, pull-up, or listener state. |
| Reset | `BYE` | Reset GPIO/listener state for the node. |

### Command ordering

`DIR` establishes the pin's direction and initializes its GPIO state. A direction change resets pull-up state to off. Configure direction before relying on `GET`, `SET`, `PLL`, or `LSN`.

`PLL` is meaningful for initialized inputs. `SET` acts on initialized outputs. `LSN` reports changes on initialized inputs. Grouped forms apply only to pins for which the operation is meaningful and skip pins that do not qualify.

## Responses

All successful and error responses keep the original request ID and name the responding source node.

| Response | Meaning |
| --- | --- |
| `HII <3` | Reply to `HAI`. |
| `IAM SAM4E8E GPIO <3` | Current SAM status reply to `HRU`. |
| `MAP BANK <bank> <3` | One bank record in a `MAP` stream. |
| `MAP PIN <target> <package-pin|-> <bank> <bit> <capabilities> <3` | One pin record in a `MAP` stream. |
| `OKA <3` | Successful acknowledgement or grouped-response terminator. |
| `HYG <pin> LOW <3` / `HYG <pin> HIGH <3` | Pin value or listener event. |
| `HYG <pin> DIR <value> <3` | Direction state. Value is `IN`, `OUT`, or `UNSET`. |
| `HYG <pin> PLL <value> <3` | Pull-up state. Value is `ON`, `OFF`, or `UNSET`. |
| `HYG <pin> LSN <value> <3` | Listener state. Value is `ON`, `OFF`, or `UNSET`. |
| `UMM BAD_PACKET <3` | A known request form was malformed. |
| `UMM <pin> UNSET <3` | An individual operation required an initialized pin. |
| `UMM <pin> UNAVAILABLE <3` | An individual operation addressed an unavailable/reserved pin. |
| `UMM NO_ROUTE <destination> <3` | This node has no configured path to the requested destination. |
| `UMM ROUTE_BUSY <next-hop> <3` | The bounded queue for the selected next hop cannot accept another frame. |
| `UMM ROUTE_DOWN <next-hop> <3` | The selected next-hop link reported a hard failure. |
| `IDK <3` | The command name is unknown. |
| `CYA <3` | Reply to `BYE`. |

If packet framing or the packet ID is malformed before a usable request ID exists, no correlated response is possible.

## Pin-map discovery

`MAP` describes the GPIO topology of the addressed node. It discovers that node's banks and pins. It does not discover routes or the network graph.

One `MAP` request streams every bank record followed by every pin record under the same request ID. `OKA <3` terminates the stream. A node with no exposed banks or pins can reply with the terminal `OKA` immediately.

Bank records have this form:

```text
070 SAM MAP BANK PIOA <3
```

Pin records have this form:

```text
070 SAM MAP PIN PA00 102 PIOA 0 7 <3
070 SAM MAP PIN PA05 73 PIOA 5 0 <3
070 SAM OKA <3
```

The pin fields are the native target token, physical package-pin number, bank token, bit/order within the bank, and capability bits. A `-` package-pin field means that the physical package pin is unknown.

Capability bits are additive: `1` means input, `2` means output, and `4` means pull-up control. For example, `7` supports all three operations, `3` supports input and output without pull-up control, `1` is input-only, and `0` marks a pin unavailable for GPIO commands. These bits describe operations implemented by the addressed node, not whether an attached board net is electrically safe to drive. MAP includes unavailable pins so a host can display the complete node topology while respecting those capability flags.

The metadata in a `MAP` response is the same topology that the node uses when it resolves later GPIO target tokens. A host must discard a partial map if the stream fails before the terminal `OKA`.

## Individual and grouped operations

An individual target produces its normal direct response or error. Bank and `ALL` targets are grouped operations where applicable.

`GET <bank|ALL> OK?` sends one `HYG <pin> <level> <3` response for each initialized matching pin, then finishes with `OKA <3` under the same request ID.

`WYD <bank|ALL> <query>` sends one `HYG` state response for each available matching pin, then finishes with `OKA <3` under the same request ID.

Grouped mutations such as `DIR`, `SET`, `PLL`, and `LSN` apply to the matching eligible pins and finish with `OKA <3`. Unavailable pins are skipped rather than turning the whole grouped operation into an error.

Example grouped read:

```text
020 SAM GET PIOC OK?
020 SAM HYG PC00 LOW <3
020 SAM HYG PC01 HIGH <3
020 SAM OKA <3
```

The exact number of `HYG` lines depends on current pin state and the chosen operation.

## Listener lifecycle

A successful listener-enable request is persistent. The acknowledgement and every later change notification use the original request ID:

```text
030 SAM LSN PA00 ON OK?
030 SAM OKA <3
030 SAM HYG PA00 HIGH <3
030 SAM HYG PA00 LOW <3
```

`LSN PA00 OFF OK?` stops that listener. Re-enabling/replacing a listener transfers future events to the new request ID only after the new request succeeds. `BYE` clears all listener state.

Grouped listener setup follows the same rule: one request ID identifies the listeners created by that grouped request until a later command stops, replaces, or resets them.

## Reset behavior

`BYE` resets initialized pins to input with pull-up off, clears listener state, and forgets the node's GPIO configuration state. The response is:

```text
040 SAM BYE
040 SAM CYA <3
```

After reset, pins are `UNSET` again from the protocol's point of view.

## Error examples

Malformed known command:

```text
050 SAM DIR PA00 SIDEWAYS OK?
050 SAM UMM BAD_PACKET <3
```

Unknown command:

```text
051 SAM WAT PA00
051 SAM IDK <3
```

Unavailable pin:

```text
052 SAM DIR PB08 OUT OK?
052 SAM UMM PB08 UNAVAILABLE <3
```

Uninitialized individual read:

```text
053 SAM GET PA00 OK?
053 SAM UMM PA00 UNSET <3
```

Unknown route:

```text
054 XYZ HAI
054 SAM UMM NO_ROUTE XYZ <3
```

The response source identifies the node that failed the route lookup. In this example, that node is `SAM`. The `NO_ROUTE` argument preserves the unresolved destination.

## Routed forwarding

A node can configure one or more downstream next hops. One next hop can serve several destination names. The router selects a next hop from the request destination and forwards the complete request frame without changing its ID, destination, or command body.

Downstream responses and listener events travel upstream as complete frames. Intermediate nodes do not rewrite their IDs or source names.

The current SAM firmware configures one downstream route named `LPC` over SAM UART1. The router forwards a request such as `054 LPC HAI` unchanged. An LPC reply such as `054 LPC HII <3` returns to the host unchanged with the same host-allocated ID.

If a link temporarily cannot make progress, the router keeps accepted frames in a fixed-capacity queue. Temporary flow control does not mean that the route is down. When that queue is full, a new request fails locally:

```text
060 LPC HAI
060 SAM UMM ROUTE_BUSY LPC <3
```

If the next-hop adapter reports a hard failure, the request fails with `ROUTE_DOWN` instead:

```text
061 LPC HAI
061 SAM UMM ROUTE_DOWN LPC <3
```

The error argument names the failed next hop, while the response source names the node that detected the routing failure.

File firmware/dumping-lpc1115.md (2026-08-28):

# Dumping the LPC1115 Firmware

To dump the LPC1115 firmware, we need:

- HW: SWD debugger: A Pi Pico works perfectly too.
- HW: soldering iron
- SW: OpenOCD

## Getting Started

Firstly, make sure you have [OpenOCD](https://openocd.org/) installed on your computer. I am using version 0.12.0

Then, flash the pico with [DebugProbe firmware](https://github.com/raspberrypi/debugprobe/releases). Download the "on_pico.tf2" version according to your pico version (pico v1.0 vs pico v2.0). I am using v2.3.1

Hold the bootsel button on the pico while plugging it in, and release after a few seconds. Make sure you see a ~128MB drive appear, and drag and drop the firmware file onto it. It will automatically disconnect, dont worry, its normal

After the firmware is flashed, check that its recognized:

```shell
openocd -f interface/cmsis-dap.cfg -f target/lpc11xx.cfg -c "init" -c "shutdown"
```

> If you see `Error: unable to find a matching CMSIS-DAP device`, check your USB connection to the pico and try again.

If the device is recognized, you should see something like:

```shell
Info : Using CMSIS-DAPv2 interface with VID:PID=0x2e8a:0x000c, serial=E661410403381C2C
Info : CMSIS-DAP: SWD supported
Info : CMSIS-DAP: Atomic commands supported
Info : CMSIS-DAP: Test domain timer supported
Info : CMSIS-DAP: FW Version = 2.0.0
Info : CMSIS-DAP: Interface Initialised (SWD)
Info : SWCLK/TCK = 0 SWDIO/TMS = 0 TDI = 0 TDO = 0 nTRST = 0 nRESET = 1
Info : CMSIS-DAP: Interface ready
Info : clock speed 10 kHz
Error: Error connecting DP: cannot read IDR
```

> The error is normal, as the device is not connected to the board yet.

If everything until this point is working, continue by finding the J114 connector on the board. It should be located between the MCU's, and next to the buzzer and the flash memory.

Find the pin 1 (on my board, its square shaped and has a small '1' printed next to it). Then, solder the wires according to this table:

| Board pin | Pin description | SWD pin | Pico pin |
| :---: | :---: | :-----: | :---: |
| 1 | 5V | - | - |
| 2 | SWDIO |  SWDIO  | GP3 |
| 3 | GND | GND | GND |
| 4 | GND | - | - |
| 5 | SWDCLK | SWDCLK  | GP2 |
| 6 | RESET | - | - |

> _Huge thanks to pyr0ball for this schematic: [Pyr0ball (GitHub)](../SOURCES.md#pyr0ball-schematic)_

| J114 connector with the cables soldered | Pico with the cables soldered |
| --- | --- |
| J114 connection | Pico after soldering |

At this point, you should have a Pico with the SWD pins connected to the board. If you are using a different board, you can refer to the SWD pin column instead.

> Do NOT connect the SWD pins to the pico's pins marked 'SWDIO', 'SWDCLK' etc, they are for debugging the pico itself, and you will end up spending too much time chasing ghosts (dont ask how i know)

Double check the connections and make sure there are no shorts or wrong connections! They can cook your printer board, your debugger, or your computer!

## Verifying the Connection

After you are sure everything is correct, continue by connecting the printer board to power, and the pico to your computer. Check the connection again:

```shell
openocd -f interface/cmsis-dap.cfg -f target/lpc11xx.cfg -c "init; exit"
```

If the connection is correct, you should see output like this:

```shell
Info : Using CMSIS-DAPv2 interface with VID:PID=0x2e8a:0x000c, serial=E661410403381C2C
Info : CMSIS-DAP: SWD supported
Info : CMSIS-DAP: Atomic commands supported
Info : CMSIS-DAP: Test domain timer supported
Info : CMSIS-DAP: FW Version = 2.0.0
Info : CMSIS-DAP: Interface Initialised (SWD)
Info : SWCLK/TCK = 0 SWDIO/TMS = 0 TDI = 0 TDO = 0 nTRST = 0 nRESET = 1
Info : CMSIS-DAP: Interface ready
Info : clock speed 10 kHz
Info : SWD DPIDR 0x0bb11477
Info : [lpc11xx.cpu] Cortex-M0 r0p0 processor detected
Info : [lpc11xx.cpu] target has 4 breakpoints, 2 watchpoints
Info : starting gdb server for lpc11xx.cpu on 3333
Info : Listening on port 3333 for gdb connections
```

> If there are any problems, you can try decreasing the clock speed:
>
> ```shell
> # For 1 kHz:
> openocd -f interface/cmsis-dap.cfg -f target/lpc11xx.cfg -c "adapter speed 1" -c "init" -c "shutdown"
> ```

## Checking for CRP (Code Readout Protection)

At this point, you should have your computer successfully communicating with the printer board over the SWD interface.

Here, we check for CRP (Code Readout Protection) before attempting to dump the firmware.

> **What is CRP?**
>
> Code Readout Protection is a security feature that prevents the firmware from being read out of the device.
> Good for protecting IP, bad for reverse engineering or backing up the firmware.
>
> CRP Levels
> _Source: [NXP Application Note AN10968](../SOURCES.md#datasheet-nxp-an10968)_
> More information can be found at: [NXP User Manual UM10398](../SOURCES.md#datasheet-nxp-um10398)

```shell
openocd -f interface/cmsis-dap.cfg -f target/lpc11xx.cfg -c "init" -c "halt" -c "mdw 0x2FC" -c "shutdown"
```

You should see output like this:

```shell
[lpc11xx.cpu] halted due to debug-request, current mode: Handler External Interrupt(24)
xPSR: 0x81000028 pc: 0x0000375a msp: 0x10001f84
0x000002fc: e7fee7fe

shutdown command invoked
```

The part after the '0x000002fc' in the output is the CRP level, which indicates the level of protection the device is using. It has some magic byes that indicate the level of protection as mentioned above in the 'What is CRP?' section.

| Location of the magic bytes on the chip (0x000002fc) | Magic values for the CRP setting |
| --- | --- |
| CRP Hex Location  | CRP Magic Bytes |

> _Source: [NXP Application Note AN10968](../SOURCES.md#datasheet-nxp-an10968)_

Here, i got 'e7fee7fe' as the CRP level, which is not a valid CRP level. This means the device is not protected by CRP, and the firmware can be dumped without any restrictions.

> **I got CRP level >=1, what should i do!?**
>
> I have absolutely no idea. You can try erasing the magic bytes since the firmware still allows erasing/writing in CRP1, but it doesnt use SWD. If you have CRP2, you have no way other than full erase (i think). If you have CRP3, just throw that chip in the bin and move on as that is the best you can do to preserve your sanity.
>
> Jokes aside, you should still be able to bypass the chip and directly solder the heater pins etc to the main MCU and ignore the LPC chip completely.
>
> I have also found [this video](https://www.youtube.com/watch?v=98eqp4WmHoQ), which I havent checked yet but might be helpful.

## Dumping the Firmware

At this point, you should have verified that CRP is not enabled, and the connection is solid. You can now proceed to dump the firmware.

```shell
openocd -f interface/cmsis-dap.cfg -f target/lpc11xx.cfg \
  -c "adapter speed 100" \
  -c "init" \
  -c "halt" \
  -c "dump_image lpc1115_dump.bin 0x0 0x10000" \
  -c "shutdown"
```

And you should see output similar to the following:

```shell
adapter speed: 100 kHz

Info : Using CMSIS-DAPv2 interface with VID:PID=0x2e8a:0x000c, serial=E661410403381C2C
Info : CMSIS-DAP: SWD supported
Info : CMSIS-DAP: Atomic commands supported
Info : CMSIS-DAP: Test domain timer supported
Info : CMSIS-DAP: FW Version = 2.0.0
Info : CMSIS-DAP: Interface Initialised (SWD)
Info : SWCLK/TCK = 0 SWDIO/TMS = 0 TDI = 0 TDO = 0 nTRST = 0 nRESET = 1
Info : CMSIS-DAP: Interface ready
Info : clock speed 100 kHz
Info : SWD DPIDR 0x0bb11477
Info : [lpc11xx.cpu] Cortex-M0 r0p0 processor detected
Info : [lpc11xx.cpu] target has 4 breakpoints, 2 watchpoints
Info : starting gdb server for lpc11xx.cpu on 3333
Info : Listening on port 3333 for gdb connections
[lpc11xx.cpu] halted due to debug-request, current mode: Handler External Interrupt(24)
xPSR: 0x6100000f pc: 0x00002bac msp: 0x10001f88
dumped 65536 bytes in 9.850773s (6.497 KiB/s)

shutdown command invoked
```

> If your connection cannot handle the speed, you can decrease the `adapter speed` value, which will slow down the connection but may be necessary.

At this point, you should have a `lpc1115_dump.bin` file in your current directory.

> **Optional but strongly recommended**: Dump the firmware multiple times (at least 3 times) by renaming the output file. Then, use sha256sum to make sure the dumps are identical. For example:
>
> | Dumping the firmware for the first time, and hashing the output file | Dumping the firmware for the second time, and hashing the output file |
> | -------------------------------------------------------------------- | --------------------------------------------------------------------- |
> | Dumping for the first time  | Dumping for the second time  |

If you have dumped the firmware, i would appreciate it if you could open a github issue with the sha256sum of your dump attached, in case its different. Sharing the firmware dump itself _on github_ is problematic due to takedown risk.

**SHA256: `06b5d7cf232baf1b85f75e0fae2309a2998115c4562af5db99f1687bc1e088d5`**

## Preserving the firmware dump

Make sure to preserve the firmware dump in a secure location, and try to back it up on different media (e.g. USB drive, external hard drive, cloud storage, etc.) in case you need to recover it later.

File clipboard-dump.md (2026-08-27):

## Clipboard Dump

The place where I dump my clipboard contents so I don't lose them

- https://www.soliforum.com/post/135347/#p135347
- https://docs.google.com/spreadsheets/d/1Fykc7o-pBj2Sig6lX_1IpMJtMFil4skVm5eA9VKKM8U/edit?usp=drivesdk
- https://github.com/dc42/RepRapFirmware/files/2174102/DaVinciJr_Research.Schematic.1.pdf
- https://www.soliforum.com/post/138269/#p138269
- https://github.com/Duet3D/RepRapFirmware/issues/190
- https://github.com/luc-github/Repetier-Firmware-4-Davinci/blob/master/lcd-4x16-bn.pdf
- https://www.ti.com/lit/ds/symlink/txb0108.pdf

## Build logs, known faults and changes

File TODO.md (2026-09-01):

## TODO

### Verification

- [ ] Verify endstops and filament sensor
- [x] Document and verify the buttons and buzzer
- [x] Document and verify the LCD
- [x] Document and verify the SD card reader
- [x] Document and verify the hotend

### Identification

- [x] Identify the LCD
- [x] Identify the buzzer
- [x] Identify the SD card reader
- [x] Identify the endstops
- [x] Identify the filament sensor
- [x] Identify and image the hotend board
- [x] Identify the chip on the hotend board
- [x] Identify the sensors on the hotend board

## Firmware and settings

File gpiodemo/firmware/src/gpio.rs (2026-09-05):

pub use da_vinci_protocol::PinCapabilities as Capabilities;
use da_vinci_protocol::{
    DecodedRequest, Direction, Level, Packet, Query, QueryValue, RequestId, Response,
    ResponseError, TargetError,
};

pub const MAX_PINS: usize = 128;
pub const MAX_BANKS: usize = 8;

#[derive(Clone, Copy, Debug, PartialEq, Eq)]
pub struct PinId(u8);

impl PinId {
    pub const fn new(index: u8) -> Self {
        Self(index)
    }

    pub const fn index(self) -> usize {
        self.0 as usize
    }
}

#[derive(Clone, Copy, Debug, PartialEq, Eq)]
pub struct BankId(u8);

impl BankId {
    pub const fn new(index: u8) -> Self {
        Self(index)
    }

    pub const fn index(self) -> usize {
        self.0 as usize
    }
}

#[derive(Clone, Copy, Debug, PartialEq, Eq)]
pub struct BankInfo {
    pub token: &'static str,
}

impl BankInfo {
    pub const fn new(token: &'static str) -> Self {
        Self { token }
    }
}

#[derive(Clone, Copy, Debug, PartialEq, Eq)]
pub struct PinInfo {
    pub token: &'static str,
    pub package_pin: Option<u16>,
    pub bank: BankId,
    pub bit: u8,
    pub capabilities: Capabilities,
}

impl PinInfo {
    pub const fn new(
        token: &'static str,
        package_pin: Option<u16>,
        bank: BankId,
        bit: u8,
        capabilities: Capabilities,
    ) -> Self {
        Self {
            token,
            package_pin,
            bank,
            bit,
            capabilities,
        }
    }
}

#[derive(Clone, Copy, Debug, PartialEq, Eq)]
pub enum Target {
    Pin(PinId),
    Bank(BankId),
    All,
}

pub struct PinMap {
    banks: &'static [BankInfo],
    pins: &'static [PinInfo],
}

impl PinMap {
    pub const fn new(banks: &'static [BankInfo], pins: &'static [PinInfo]) -> Self {
        assert!(banks.len() <= MAX_BANKS);
        assert!(pins.len() <= MAX_PINS);
        assert!(pins.len() <= u8::MAX as usize);
        Self { banks, pins }
    }

    pub const fn banks(&self) -> &'static [BankInfo] {
        self.banks
    }

    pub const fn pins(&self) -> &'static [PinInfo] {
        self.pins
    }

    pub fn bank(&self, id: BankId) -> &'static BankInfo {
        &self.banks[id.index()]
    }

    pub fn pin(&self, id: PinId) -> &'static PinInfo {
        &self.pins[id.index()]
    }

    pub fn resolve(&self, token: &[u8]) -> Option<Target> {
        if token == b"ALL" {
            return Some(Target::All);
        }
        if let Some(index) = self
            .banks
            .iter()
            .position(|bank| bank.token.as_bytes() == token)
        {
            return Some(Target::Bank(BankId(index as u8)));
        }
        self.pins
            .iter()
            .position(|pin| pin.token.as_bytes() == token)
            .map(|index| Target::Pin(PinId(index as u8)))
    }

    pub fn pins_for(&self, target: Target) -> impl Iterator<Item = PinId> + '_ {
        self.pins
            .iter()
            .enumerate()
            .filter_map(move |(index, pin)| {
                let id = PinId(index as u8);
                match target {
                    Target::Pin(target) if target == id => Some(id),
                    Target::Bank(bank) if pin.bank == bank => Some(id),
                    Target::All => Some(id),
                    _ => None,
                }
            })
    }
}

#[derive(Clone, Copy, Debug, PartialEq, Eq)]
pub enum PinMode {
    Input { pull_up: bool },
    Output { initial: Level },
}

pub trait GpioHal {
    fn pin_map(&self) -> &'static PinMap;
    fn configure(&mut self, pin: PinId, mode: PinMode);
    fn write(&mut self, pin: PinId, level: Level);
    fn read_bank(&self, bank: BankId) -> u32;
}

type FirmwareResponse = Response<&'static [u8], &'static [u8]>;

#[derive(Clone, Copy)]
enum PinState {
    Unset,
    Configured {
        direction: Direction,
        pull_up: bool,
        listener: Option<RequestId>,
        previous: Level,
    },
}

#[derive(Clone, Copy)]
enum BulkKind {
    Values(Target),
    States(Target, Query),
    Map,
}

#[derive(Clone, Copy)]
struct BulkResponse {
    id: RequestId,
    next: usize,
    kind: BulkKind,
}

pub struct Firmware {
    identity: &'static [u8],
    pins: [PinState; MAX_PINS],
    bulk: Option<BulkResponse>,
    listener_cursor: usize,
}
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

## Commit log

2026-08-23 Document stepper motor layouts and add reference images
2026-08-24 Document verified hardware and stepper pin mappings
2026-08-24 Document E1 stepper motor pin mappings
2026-08-24 Document hotend hardware and identify flash memory chip
2026-08-24 Organize hardware documentation by board
2026-08-24 Document button mappings for interactivity controls
2026-08-25 Document sub-board hardware
2026-08-25 Initalize KiCAD schematics
    [DaVinciJr1.0.kicad_sch, HotendBoard.kicad_sch, MainBoard.kicad_sch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]
2026-08-25 Update sub-board components
2026-08-25 Document reverse-engineering progress and connectors
2026-08-25 Update hotend and other docs, update progress
2026-08-25 Progress on KiCAD schematics
    [HotendBoard.kicad_sch, MainBoard.kicad_sch, SubBoard.kicad_sch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]
2026-08-26 Update SD card connector pins
2026-08-26 Update sub-board schematic
    [SubBoard.kicad_sch]
2026-08-26 Complete SubBoard schematic tracing
    [SubBoard.kicad_sch]
2026-08-26 Add hotend board schematic
    [HotendBoard.kicad_sch, SubBoard.kicad_sch]
2026-08-26 Update board schematics
    [HotendBoard.kicad_sch, MainBoard.kicad_sch, SubBoard.kicad_sch]
2026-08-26 Start main board schematic and update hotend schematic size
    [HotendBoard.kicad_sch, MainBoard.kicad_sch]
2026-08-26 Document LCD and button connector mappings
2026-08-27 Organize hardware documentation and pinouts
    [MainBoard.kicad_sch, SubBoard.kicad_sch]
2026-08-27 Add desoldered sub-board view documentation and fix typo
2026-08-27 Document connector layouts and firmware safety warnings
2026-08-29 Updata TODO and schematics
    [MainBoard.kicad_sch, SubBoard.kicad_sch]
2026-08-29 Fix the broken button
    [SubBoard.kicad_sch]
2026-08-30 Document SAM4E pinouts and update schematic
    [MainBoard.kicad_sch]
2026-08-31 Reformat stepper docs and progress
2026-08-31 Document board power fuses and update power schematics
    [MainBoard.kicad_sch]
2026-09-01 Complete hotend documentation and schematics
    [HotendBoard.kicad_sch, MainBoard.kicad_sch]
2026-09-01 Document 51-pin hotend connector pinout
2026-09-01 Update hotend connector pinout
2026-09-01 Update hotend connector fan and heater pinouts
2026-09-01 Update EEPROM and ground pins for hotend
2026-09-01 Update main board schematic
    [MainBoard.kicad_sch]
2026-09-01 Update schematic for the drivers power rails
    [MainBoard.kicad_sch]
2026-09-01 Update schematic and progress, verify some pins
    [MainBoard.kicad_sch]
2026-09-02 Add firmware structure for firmata work (#1)
    * Add minimal SAM4E8E firmware foundation
    * Refine SAM4E8E firmware interfaces
    * Tidy firmware headers
    * Add Justfile build and flash helpers
    * Replace Makefile with Justfile
    * Added default device to Justfile
    * Update Justfile deprecated features
    * Consolidate SAM4E8E firmware layout
    * Reorganize SAM4E8E firmware layout
    * Organize the example firmware docs layout
    ---------
2026-09-04 Add GPIO demo and firmware (#4)
    * Port digital Firmata to SAM4E8E
    * Remove Firmata host tests
    * Tighten firmware compiler warnings
    * Make Firmata pin mapping explicit
    * Add firmata python library for testing
    * Fix flash recipe device argument
    * Update examples
    * Add GPIO controller demo and move firmata folder
    * Add logs window
    * Added main window
    * Speed up pin table rendering
    * Speed up pin row rendering
    * Speed up pin table scrolling
    The slow path was Tk moving and repainting one tall CTkScrollableFrame widget hierarchy on every scroll step. Draw the static/status/action cells directly on a canvas so scrolling moves canvas items instead of the nested row tree.
    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
2026-09-04 Update sub-board pinouts
2026-09-05 fix: clean up Rust GPIO rewrite
    [main.rs]
2026-09-05 feat: support ALL pin target
2026-09-05 feat: redesign GPIO controller around PIO targets
    [main.rs]
2026-09-05 fix: keep connection controls visible at minimum width
    [main.rs]
2026-09-05 fix: prevent GPIO UI text overflow
    [main.rs]
2026-09-05 refactor: name flat pin index conversion
2026-09-05 fix: reserve narrow pin action space
    [main.rs]
2026-09-05 fix: stack pin columns before text wraps
    [main.rs]
2026-09-05 fix: bound serial event processing
    [main.rs]
2026-09-05 refactor: simplify synchronous GUI flow
2026-09-05 refactor: centralize pin target iteration
2026-09-05 perf: sample listeners by PIO bank
2026-09-05 fix: preserve configured pin protocol parity
2026-09-05 docs(protocol): document routed wire contract (#25)
2026-09-05 refactor(firmware): extract framed transport (#26)
2026-09-05 refactor(firmware): move GPIO engine behind HAL pin maps (#21)
2026-09-05 feat(firmware): route LPC over SAM UART1 (#23)
2026-09-05 feat(gpio): discover route-local pin maps (#28)
2026-09-05 fix(firmware): preserve frame error semantics (#33)
2026-09-05 refactor(firmware): consolidate LPC pin metadata (#35)
2026-09-05 refactor(firmware): unify pin configuration (#36)
2026-09-05 refactor(host): centralize device session state (#40)
2026-09-05 fix(gui): make pin-map discovery explicit (#56)
2026-09-05 refactor(protocol): single-source fixed wire values (#47)
2026-09-05 feat(protocol): add bounded owned frame (#49)
2026-09-05 feat(protocol): add message frame conversions (#50)
2026-09-05 refactor(gui): use protocol message frame seam (#51)
2026-09-05 refactor(firmware): use protocol message frame seam (#52)
2026-09-05 refactor(gui): delegate pin actions to scopes (#68)
2026-09-05 refactor(gui): keep serial writes as frames (#69)
2026-09-05 refactor(protocol): emit frames from LineBuffer (#70)
2026-09-05 refactor(firmware): route typed frames end to end (#71)
2026-09-05 refactor(gui): decode ordinary frames in session (#76)
